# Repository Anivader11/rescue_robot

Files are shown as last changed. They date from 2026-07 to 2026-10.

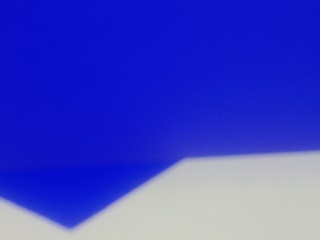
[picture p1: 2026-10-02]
rescue_robot/line_follow/cam_check.jpg

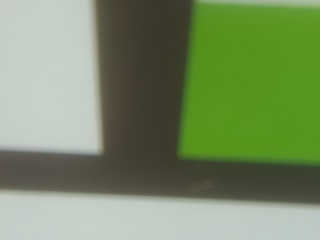
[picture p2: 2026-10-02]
rescue_robot/cam_check.jpg

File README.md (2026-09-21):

# Rescue Line Robot

RoboCup Junior Rescue Line robot running on a Raspberry Pi 5. Two-wheel
differential drive on RoboMaster M2006 P36 brushless motors, with digital
IR line sensors for line following and a Pi Camera Module doing the rest
of the perception (green direction markers, silver spill/endzone tape,
obstacle confirmation).

The robot used to be camera-only for line following (see
[`old_camera_version/`](old_camera_version/)); it's since moved to
dedicated IR line sensors, with the camera now doing everything that
isn't line position: markers, spill tape, and obstacle confirmation.

## Hardware

- **Compute:** Raspberry Pi 5, SSH reachable at `nigesh@rescue.local`
- **Drive:** 2x RoboMaster M2006 P36 brushless motors via Powerful BLDC
  Driver boards over I2C (front-left `0x20`, front-right `0x19`) — rear
  motors are disconnected, robot runs 2-wheel drive
- **Line sensors:** 2x digital IR line sensors (Parallax 28034-style),
  GPIO24 (left) / GPIO23 (right), spaced so that when centered on the
  line **both** read white — the line runs between them, not under
  either one
- **Camera:** Raspberry Pi Camera Module (via `picamera2`) — green
  marker detection, silver spill-zone detection, obstacle confirmation
- **ToF sensor:** SteelBar Time-of-Flight distance sensor, I2C address
  `0x51` (confirmed via `i2cdetect -y 1` — the vendor example code says
  `0x50`, that's wrong for this board)
- **IMU:** Adafruit BNO085 9-DOF orientation sensor, I2C address `0x4A`
- All I2C devices share bus 1 (GPIO2/SDA, GPIO3/SCL)

## Repo layout

```
rescue_robot/
├── line_follow/              -- active robot code (see below)
├── control/
│   └── motors.py             -- BLDC motor driver + PID controller class
├── sensor_tests/              -- standalone IR line sensor test scripts
├── old_camera_version/        -- archived camera-only line-following system
├── switch_watcher.py          -- GPIO21 physical switch: turns main.py on/off
├── rescue-robot-switch.service -- systemd unit for switch_watcher.py
├── setup_pi.sh                -- Pi provisioning script
├── requirements.txt
└── FILE_MAP.md                -- more detailed file-by-file breakdown
```

## `line_follow/` — active system

**Entry point:** `pid_line_follow.py`. Run with:
```
python3 line_follow/pid_line_follow.py
```

### Core line following

Two digital IR sensors, read once per loop tick (`LEFT_PIN=24`,
`RIGHT_PIN=23`). `error = left_val - right_val` (-1, 0, or +1 — sensors
are binary, not analog). A PD controller (`Kp=20`, `Kd=10`, no I term —
not useful with a 3-valued error signal) turns that into a differential
steering correction applied to both wheels around `BASE_SPEED`. Both
`(0,0)` (centered — line between the sensors) and `(1,1)` (on an
intersection) correctly resolve to error `0` and drive straight; there's
no separate "line lost" failsafe.

### Camera subsystem — `camera_watcher.py`

Only one physical camera exists on the robot, so a single shared
`Picamera2` thread runs every camera-based check on the same captured
frame, instead of each detector opening its own camera (which would
conflict):

- **Green marker detection** — HSV threshold + largest-contour check,
  reports which side (`left`/`right`) a green marker was seen on. Resets
  to `None` when nothing's detected that frame (doesn't get stuck on the
  last reading).
- **Spill/endzone tape detection** — `spill_classifier.py`, a trained
  Random Forest classifier (95.6% test accuracy) running on features
  extracted from a fixed center box each frame. See "Spill-zone ML
  pipeline" below for how it was built. Classical CV approaches
  (brightness threshold, saturation threshold, local std-dev, top-hat
  filter) were all tried first and failed — the tape and tile are close
  to indistinguishable pixel-by-pixel; only a trained classifier over
  whole-region features worked reliably.
- **`get_frame()`** — exposes the latest raw frame so other code
  (`bottle_detector.py`) can run its own one-off check on demand without
  opening a second camera.

`green_detector.py` and `spill_detector.py` are kept as standalone
single-purpose versions of the same logic (useful for isolated testing)
but aren't imported by `pid_line_follow.py` anymore — `camera_watcher.py`
replaced both.

### Obstacle handling — ToF + camera confirmation

`tof_sensor.py` is a Python port of the SteelBar ToF sensor's I2C
protocol (register `0x10`, 5-byte read: sequence number + signed
little-endian distance in mm). `tof_detector.py` polls it in a background
thread.

The ToF alone can't tell a ramp from an actual obstacle (both can read
within 50mm), so when it triggers, `bottle_detector.py` checks the
latest camera frame before committing to anything: since the obstacle
(a 1.25L clear water bottle) has no reliable color to threshold on, it
looks for shape instead — Canny edges + a Hough line transform, checking
whether the scene is dominated by near-vertical lines (a bottle's two
side edges + its cylindrical highlight) rather than the diagonal/
horizontal edges a ramp's sloped face would produce. Only if the camera
confirms it does `obstacle_evade.py` run its fixed timed evasion
maneuver (back → right → forward → left → straight → left → right, then
resume line following); otherwise it's treated as a ramp and normal line
following just continues.

`bottle_detector.py`'s shape heuristic is untested on real hardware —
tune `MIN_VERTICAL_LINES` / `VERTICAL_LINE_RATIO_THRESHOLD` against the
actual bottle and ramp once you can test on the Pi (standalone test mode:
`python3 line_follow/bottle_detector.py`, using a laptop webcam).

### Ramp speed boost — IMU

`imu_sensor.py` wraps the Adafruit BNO085 (`adafruit-circuitpython-bno08x`)
and reports raw accelerometer/gyroscope/magnetometer values. A background
thread, `accel_speed_boost.py`, watches raw Y acceleration; level ground
reads around `Y=-9.8` (gravity), and once `Y` drops below `-15.0`
(nosing upward onto a ramp), `pid_line_follow.py` multiplies `BASE_SPEED`
by 1.5 (+50%) until `Y` comes back above the threshold.

### Spill-zone ML pipeline (how `spill_model_weights.py` was built)

1. `collect_spill_samples.py` (laptop webcam) / a Pi-side collector —
   capture labelled samples (silver tape vs. tile, including tricky
   negatives like shadows/the black line) into `spill_samples.csv`.
   Features per sample: mean R/G/B, mean H/S/V, brightness, std_dev,
   max, min, range — all measured over a fixed 150x150px center box.
2. `train_spill_classifier.py` (laptop, needs `scikit-learn`) — trains
   both `LogisticRegression` and `RandomForestClassifier`, picks whichever
   scores higher on a held-out split, and exports the winner as plain
   Python data (`spill_model_weights.py`) with **no sklearn dependency**.
3. `spill_classifier.py` — pure-numpy inference on the Pi, no sklearn
   needed at runtime. Supports both model types the trainer might export.

To retrain: collect more samples into `spill_samples.csv`, rerun
`train_spill_classifier.py`, copy the regenerated `spill_model_weights.py`
onto the Pi.

### Test/calibration utilities

- `test_forward.py` — drives both wheels forward briefly, for verifying
  `control/motors.py`'s `MOTOR_CONFIG` calibration values after a power
  cycle (the BLDC driver boards' `elec_angle_offset`/`sincos_centre`
  reset when they lose power — re-run a calibration tool and paste fresh
  values into `MOTOR_CONFIG` when that happens)
- `test_green_webcam.py`, `test_spill_webcam.py`,
  `test_spill_classifier_webcam.py` — standalone webcam test harnesses
  for the camera detectors, without needing the full robot loop running
- `calibrate_spill_webcam.py` — measures brightness/color/std-dev
  differences between the silver tape and white tile, used while
  designing the spill detection approach

## `control/motors.py`

`BLDCMotorDriver` — real I2C driver for the two front M2006 motors via
the `steelbar_powerful_bldc_driver` library. Sign convention: right side
positive, left side negative = forward. `MOTOR_CONFIG` holds per-motor
I2C address + calibration values that must be refreshed after any power
cycle of the driver boards.

Also includes `PIDController` (a more general PID used elsewhere) and
`StubMotorDriver` (prints commands instead of driving hardware, for
testing without the robot).

## `sensor_tests/`

Standalone scripts for bringing up and verifying the IR line sensors in
isolation, before they're wired into the main loop.

## `old_camera_version/`

Archived: the original all-camera line-following system (HSV-threshold
line detection instead of IR sensors, PID over camera-estimated line
position). Kept for reference; not run anymore.

## `switch_watcher.py` + `rescue-robot-switch.service`

Watches a physical GPIO21 switch: ON starts `line_follow/pid_line_follow.py`
as a subprocess, OFF stops it. Installed as a systemd service so it
starts on boot:
```
sudo cp rescue-robot-switch.service /etc/systemd/system/
sudo systemctl daemon-reload
sudo systemctl enable --now rescue-robot-switch.service
```

## Setup

```
bash setup_pi.sh                 # Pi provisioning
pip install -r requirements.txt
pip install adafruit-circuitpython-bno08x adafruit-blinka   # for imu_sensor.py
pip install git+https://github.com/Aw3someAndrew/SteelBar_CircuitPython_powerful_bldc_driver.git
```

See `FILE_MAP.md` for a more granular file-by-file reference.

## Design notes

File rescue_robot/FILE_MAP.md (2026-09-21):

# File Map — Rescue Robot Project

Current layout after pivoting from camera-based line following to digital IR
line sensors. Kept in the project root as a quick reference.

```
rescue_robot/
│
├── control/
│   └── motors.py                  ← BLDCMotorDriver, unchanged, still used
│
├── line_follow/                   ← ACTIVE line-following system
│   ├── pid_line_follow.py         ← entry point, run this to start the robot
│   └── green_detector.py          ← background camera thread, green marker side detection
│
├── sensor_tests/                  ← GPIO/sensor diagnostic scripts (reference only)
│   ├── test_28034_line_sensor.py
│   ├── test_28034_line_sensor_rawlgpio.py
│   └── test_minimal.py            ← simplest confirmed-working sensor read
│
├── switch_watcher.py              ← boot switch watcher, launches line_follow/pid_line_follow.py
├── rescue-robot-switch.service    ← systemd unit for switch_watcher.py
├── requirements.txt
├── setup_pi.sh
├── README.md
├── FILE_MAP.md                    ← this file
│
└── old_camera_version/            ← ARCHIVE, not run anymore
    ├── main.py                    ← old entry point
    ├── vision/                    ← old camera line/marker/obstacle detection
    ├── tests/
    ├── control/
    │   ├── state_machine.py       ← old robot state machine (LINE_FOLLOWING/LOST/etc)
    │   └── shared_vision.py
    ├── calib.py
    ├── calibrate.py
    ├── calibrate_obstacle.py
    ├── calibrate_once.py
    ├── calibration_offsets.json
    ├── example.py
    ├── test_drive_calibration.py
    ├── test_forward.py
    ├── test_forwardreal.py
    ├── test_forwardv2.py
    ├── test_individual.py
    ├── test_individual_livecal.py
    ├── test_turn.py
    ├── push_test_forwardv2.sh
    ├── Rescue_Line_Robot_Code_Documentation.docx
    ├── __pycache__/
    └── _to_delete/
```

## Running the robot

```bash
python3 line_follow/pid_line_follow.py
```

or just flip the physical switch (systemd runs `switch_watcher.py`, which
launches the above automatically).

## Pushing updated files to the Pi

From your laptop, inside the `rescue_robot` folder (Windows example):
```
scp "path\to\rescue_robot\line_follow\pid_line_follow.py" nigesh@rescue.local:~/rescue_robot/line_follow/pid_line_follow.py
scp "path\to\rescue_robot\line_follow\green_detector.py" nigesh@rescue.local:~/rescue_robot/line_follow/green_detector.py
```

Make sure the destination folder exists first:
```
ssh nigesh@rescue.local "mkdir -p ~/rescue_robot/line_follow ~/rescue_robot/sensor_tests"
```

## Verifying the structure is correct

```bash
find rescue_robot -name "*.py" -not -path "*/old_camera_version/*" | sort
```
Should list exactly: `control/motors.py`, `line_follow/pid_line_follow.py`,
`line_follow/green_detector.py`, `sensor_tests/test_28034_line_sensor.py`,
`sensor_tests/test_28034_line_sensor_rawlgpio.py`,
`sensor_tests/test_minimal.py`, `switch_watcher.py`.

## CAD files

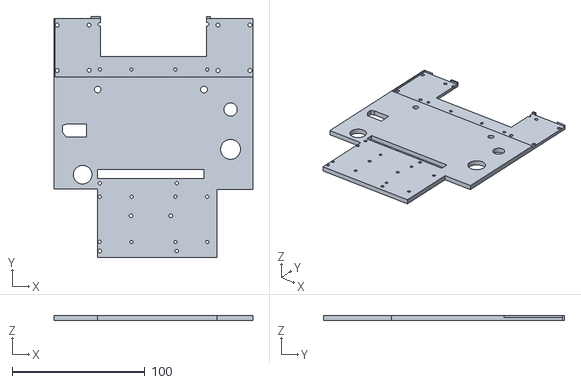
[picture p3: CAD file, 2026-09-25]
design/robot V1 main base revised.stl
149.7 x 181.4 x 4.00

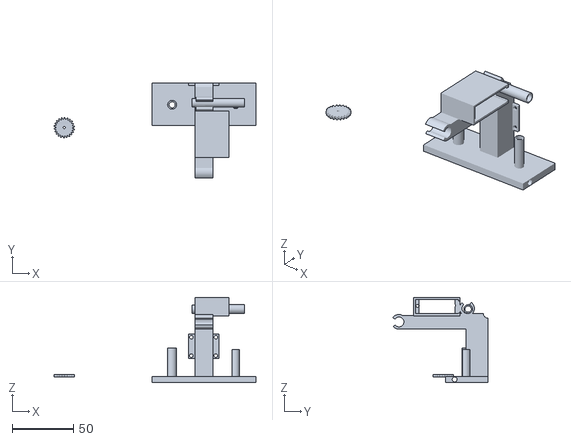
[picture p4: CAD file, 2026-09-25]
design/full_light_sensor_carriage.stl
165.0 x 77.9 x 69.5

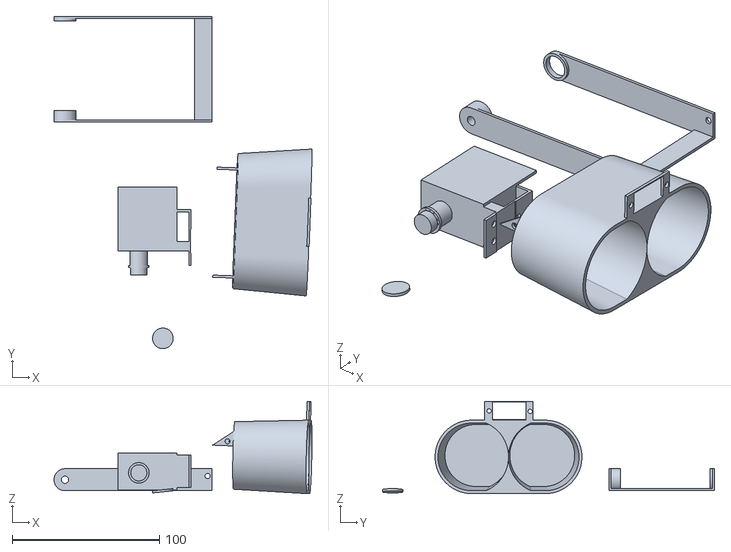
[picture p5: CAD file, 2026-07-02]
design/fullclawassembly.stl
175.5 x 226.0 x 62.8

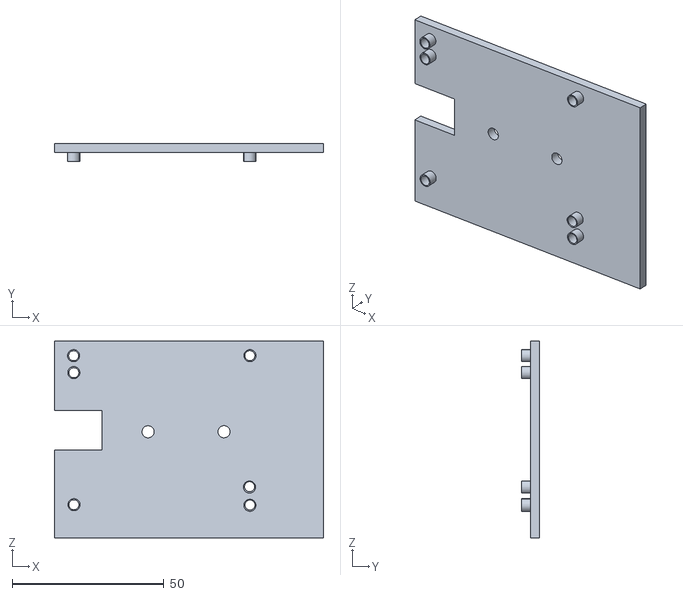
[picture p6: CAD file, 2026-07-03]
final-pi-base.stl
88.6 x 6.00 x 64.8

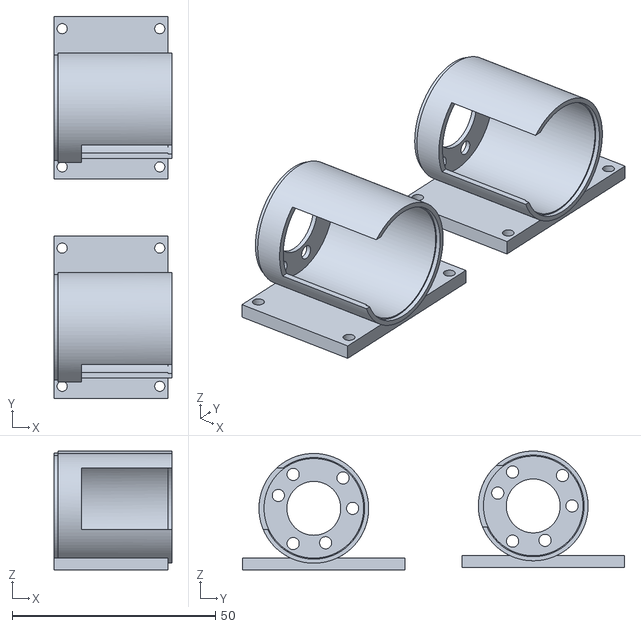
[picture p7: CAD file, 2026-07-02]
design/finalmotormount.stl
29.0 x 94.0 x 29.3

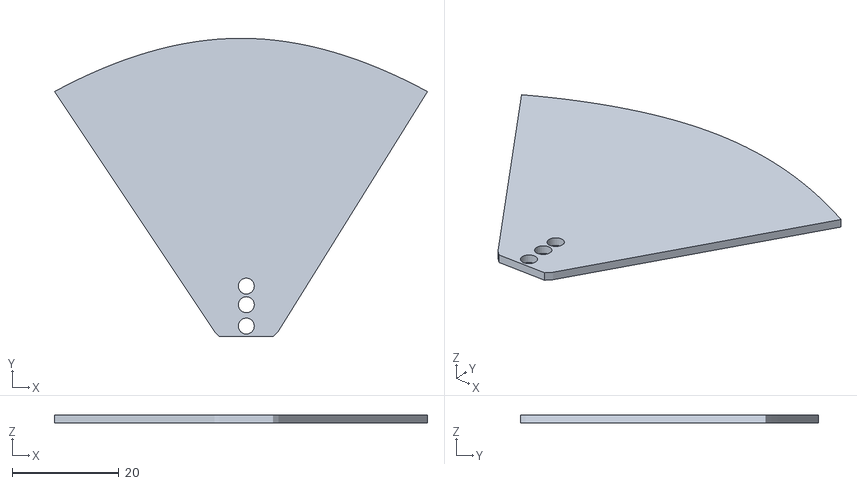
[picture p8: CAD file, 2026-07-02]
design/clawpalm.stl
70.0 x 56.0 x 1.50

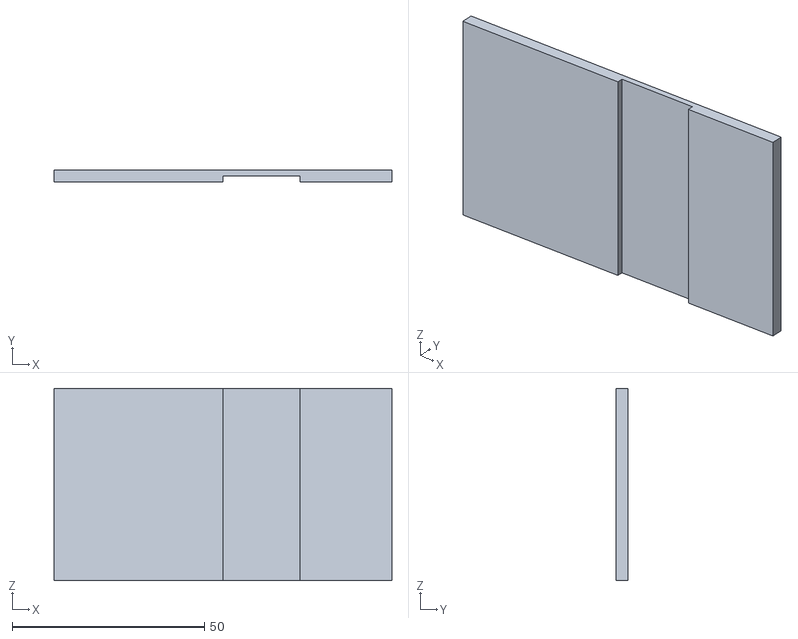
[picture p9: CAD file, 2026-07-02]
design/belowbatteryplate.stl
88.0 x 3.00 x 50.0

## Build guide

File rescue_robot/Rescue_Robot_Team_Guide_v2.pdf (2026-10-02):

Rescue Robot Team Guide | Page 1

# Rescue Robot

# Team Guide

## RoboCup Junior Australia - Open Rescue Line 2026 Melbourne High School

What is in this guide? 1. How our robot works (the simple version) 2. Setting up your laptop, then step by step: put code on the robot and run it 3. The important files and what each one does 4. The numbers you can change to make the robot behave better 5. Test scripts to check each part works 6. The problems we still have right now 7. What to do when you see an error 8. How to ask AI for help

GOOD TO KNOW: You do NOT need to understand all the code. You only need to know which file to run, how to copy it to the robot, and which number to change. This guide shows you all three. Everything here is done from your own laptop.

# 1. How our robot works

### Think of the robot as having eyes, a brain and muscles:

Part | What it is | What it does
Brain | Raspberry Pi (name: rescue.local) | Runs our Python code. We log in to it from a laptop.
Line eyes | 8 IR sensors in a row under the front (Parallax #28034) | Each sensor says black (1) or white (0). Together they tell us where the black line is.
Camera | Pi camera on a servo arm | Sees green squares, the silver tape, balls and the coloured triangles.
Distance sensor | ToF sensor, 19 mm off the floor, at the front | Measures how far away something is in front (in mm).
Tilt sensor | IMU (BNO085) | Tells us when we are going up a ramp so we can speed up.
Muscles | 2 front wheel motors (rear right motor is broken) | Drive and turn the robot.
Claw | On the BACK of the robot. 2 servos: open/close + lift | Picks up balls in the evacuation zone.

How line following works, in one sentence: 80 times every second, the robot reads the 8 sensors, works out how far the line is from the middle, and steers back toward it. The further off the line is, the harder it steers. This is called PID.
The error number: the code turns the 8 sensors into one number called the error. 0 means the line is right in the middle. +3.5 means it is all the way at one end (OUT0), -3.5 means all the way at the other end (OUT7).

### What it does at special places:

Situation | What the robot does
Line lost (all 8 sensors white) | Spins on the spot toward the last way it was turning (LEFT or RIGHT) until it sees the line again.
Green square | Stops for 1 s, checks again which side the green is on (votes), drives forward a little, then turns that way.
Sharp 90 degree corner after a straight | Drives forward a little so the wheels reach the corner, then pivots.
U-turn / two lines seen at once | Follows only the line closest to where it was before. Slows down in sharp bends.
Silver tape (evacuation zone) | Only in pid_line_follow.py: stops, checks, then runs the endzone code.
Obstacle (bottle) | Currently TURNED OFF (USE_TOF = False).

# 2. Set up YOUR laptop (do this only once)

Everyone uses their own laptop. The Pi on the robot holds the team's real, up-to-date copy of the code. Your laptop gets a copy from the Pi, you change it, and you send it back.

GOOD TO KNOW: Think of the Pi as the team's shared notebook. Always read the newest page from it before you write, and put your page back when you are done.

## Setup 1 - Check your laptop can talk to the Pi

Windows: press the Windows key, type PowerShell, press Enter. Mac: open Terminal (Cmd + Space, type Terminal).

Type this (robot must be switched on, same Wi-Fi):

ssh nigesh@rescue.local
The first time it asks "Are you sure you want to continue connecting?" - type yes and press Enter. Then type the Pi password (ask the team). If you see nigesh@rescue:~ $, it works. Type exit to go back to your laptop.

## Setup 2 - Download the code from the Pi to your laptop

Windows PowerShell (on your laptop):

scp -r nigesh@rescue.local:~/rescue_robot "$HOME\Documents\"

Mac Terminal (on your laptop):

scp -r nigesh@rescue.local:~/rescue_robot ~/Documents/
This copies the whole rescue_robot folder into your Documents folder. -r means "copy the folder and everything inside it".

## Setup 3 - Install a code editor (recommended)

Download Visual Studio Code (free) from code.visualstudio.com. Open it, then File -> Open Folder -> Documents -> rescue_robot. You can now click on any file to read or change it. Notepad also works if you can't install anything.

## Your folder paths (use these everywhere in this guide)

Where | Folder
Your laptop (Windows) | $HOME\Documents\rescue_robot\line_follow ($HOME = your user folder)
Your laptop (Mac) | ~/Documents/rescue_robot/line_follow
The Pi | ~/rescue_robot/line_follow (~ means /home/nigesh)
Pi login | nigesh@rescue.local

CAREFUL: Only ONE person sends files to the Pi at a time. If two people change the same file on their own laptops and both copy it to the Pi, the second one wipes out the first one's change. Say in the team chat "I'm pushing pid_line_follow_no_endzone.py" before you copy.

# 2. (continued) Step by step: every time you work on the robot

The code lives in two places: on your laptop (where you edit it) and on the Pi (where it runs). When you change a file on your laptop, you must copy it to the Pi or the robot will still run the old version.

GOOD TO KNOW: Golden rule: get the latest from the Pi -> edit on your laptop -> copy back with scp -> run on the Pi.

## Step 1 - Turn on the robot and connect to the same Wi-Fi

Turn the robot on and wait about 1 minute for the Pi to start. Your laptop must be on the same network as the Pi.

## Step 2 - Open PowerShell (Windows) or Terminal (Mac) on your laptop

A window opens where you type commands. Everything in a grey box marked on your laptop goes here.

## Step 3 - Get the latest code from the Pi

Windows PowerShell (on your laptop):

scp -r nigesh@rescue.local:~/rescue_robot "$HOME\Documents\"

Mac Terminal (on your laptop):

scp -r nigesh@rescue.local:~/rescue_robot ~/Documents/
CAREFUL: This REPLACES the copy on your laptop with the Pi's copy. If you changed something on your laptop and haven't sent it to the Pi yet, send it first (Step 5) or it will be lost.

## Step 4 - Go into the code folder and make your change

Windows PowerShell (on your laptop):

cd "$HOME\Documents\rescue_robot\line_follow"

Mac Terminal (on your laptop):

cd ~/Documents/rescue_robot/line_follow
cd means "change directory" = go into that folder. Now open the file in VS Code, change the number, and save (Ctrl + S, or Cmd + S on Mac).

## Step 5 - Copy the file(s) to the Pi with scp

Copy one file (on your laptop, inside the line_follow folder):

scp pid_line_follow_no_endzone.py nigesh@rescue.local:~/rescue_robot/line_follow/

Copy ALL the main files at once (on your laptop - safest after big changes):

scp camera_servo.py camera_watcher.py zone_vision.py endzone.py claw.py test_endzone.py aim_camera.py bottle_detector.py pid_line_follow_no_endzone.py pid_line_follow.py pid_line_follow_only.py nigesh@rescue.local:~/rescue_robot/line_follow/
It will ask for the Pi's password. Type it (you will NOT see the letters appear - that is normal) and press Enter. Each file prints 100% when it worked.

CAREFUL: If a file says Permission denied, it did NOT copy. See section 7 for the fix.

## Step 6 - Log in to the Pi with ssh

On your laptop:

ssh nigesh@rescue.local
Type the password. When it works, the start of the line changes to something like nigesh@rescue:~ $. Now everything you type runs on the robot.

## Step 7 - Go to the project folder on the Pi

On the Pi (after ssh):

cd ~/rescue_robot

## Step 8 - Set the camera angle by hand

Gently move the camera arm by hand to the angle that works for line following (the one we found best). The line-following code does NOT move the camera any more, so it stays where you put it.

## Step 9 - Put the robot on the line and run the code

On the Pi - the main file to use for now:

python3 line_follow/pid_line_follow_no_endzone.py

### Check the first lines it prints. You should see something like:

[version: lost-line -> spin on the spot toward last LEFT/RIGHT turn, LOOP_HZ=80]
If you do NOT see this line, the Pi has an OLD copy. Go back to Step 5.

## Step 10 - Stop the robot

Press Ctrl + C in the window. The motors stop. Pick the robot up if it is about to fall off.

## Step 11 - Log out of the Pi

On the Pi:

exit
You are now back on your laptop.

# Other useful things to do

## Change a number (tune the robot)

1. Open the file on the laptop (e.g. in VS Code or Notepad).
2. Find the number near the TOP of the file (all the settings are at the top, in CAPITAL LETTERS).
3. Change it and save (Ctrl + S).
4. Copy it to the Pi again (Step 5).
5. Run it again (Step 9).

TIP: Only change ONE number at a time, and write down what you changed and what happened. Otherwise you will not know which change helped.

## Look at what the camera sees

On the Pi:

python3 line_follow/aim_camera.py
Type a servo number (like 0.3) and press Enter. It moves the camera, holds it there, and saves a picture. Then on your laptop (open a second PowerShell/Terminal window, go to your rescue_robot

### folder):

Windows (on your laptop):

scp nigesh@rescue.local:~/cam_check.jpg . ; start cam_check.jpg

Mac (on your laptop):

scp nigesh@rescue.local:~/cam_check.jpg . ; open cam_check.jpg
This copies the picture to the laptop and opens it. Type q on the Pi to quit aim_camera.

## Edit a file directly on the Pi (quick fix only)

On the Pi:

nano line_follow/pid_line_follow_no_endzone.py
Use the arrow keys to move. Ctrl + O then Enter = save. Ctrl + X = quit.

CAREFUL: If you edit on the Pi, your laptop copy is now old. Before you change anything on your laptop again, get the latest from the Pi first (Step 3), or your next copy will undo the Pi change.

## Where the files are

Place | Path
Your laptop (Windows) | $HOME\Documents\rescue_robot\line_follow
Your laptop (Mac) | ~/Documents/rescue_robot/line_follow
Pi | ~/rescue_robot/line_follow (~ means /home/nigesh)
Pi login | nigesh@rescue.local

# 3. The important files

All of these are in the line_follow folder unless it says otherwise.

## Files you RUN

File | What it does | Use it when...
pid_line_follow_no_endzo ne.py | Main program right now. Line following + green squares + corners + U-turns. Ignores silver tape and has NO endzone. | Testing the course. Use this one most of the time.
pid_line_follow.py | Same as above PLUS silver tape detection and the evacuation zone. | Full runs - but NOT yet (see Problems: silver detector).
pid_line_follow_only.py | ONLY line following. No camera, no green, no obstacles. | Tuning Kp / Kd / speed on plain line tiles.
test_endzone.py | Runs the evacuation zone code by itself. Put the robot at the zone entrance. | Testing balls + claw + triangles. Add a number for how many balls: test_endzone.py 3
zone_vision.py | Camera-only test in the zone. Prints balls/triangles it sees, saves ~/ez_debug.jpg. | Checking the camera can see balls/triangles BEFORE driving.
camera_watcher.py | Camera-only test. Prints green side + silver, saves ~/cam_check.jpg. | Checking green-square detection.
aim_camera.py | Move the camera servo to a number you type and save a picture. | Finding good camera angles.
../sensor_tests/test_lin e8.py | Shows the 8 line sensors live, like ..##.... | Checking the line sensor wires work.

## Helper files (other files use these - you rarely run them yourself)

File | What is inside
camera_watcher.py | Runs the camera in the background. Finds green squares and which side of the black line they are on. Also flips the picture (the camera is mounted upside down).
camera_servo.py | Moves the camera arm. Has the angle numbers LINE_VALUE and LOOK_UP_VALUE.
endzone.py | The evacuation zone plan: find ball -> drive to it -> turn 180 -> grab -> find triangle -> drop.
zone_vision.py | Finds balls (silver = alive, black = dead) and the red/green triangles in a picture.
claw.py | Open, close, lower and lift the claw.
../control/motors.py | Talks to the motor drivers. set_speeds(left, right), -100 to 100.
tof_detector.py / tof_sensor.py | Reads the distance sensor.
bottle_detector.py / obstacle_evade.py | Checks if an obstacle is a bottle, and drives around it.
accel_speed_boost.py / imu_sensor.py | Speeds up on ramps using the tilt sensor.
spill_classifier.py / spill_model_weights.py | The trained 'is this silver tape?' detector.

GOOD TO KNOW: Files ending in .bak... are backups of older versions. If a change made things worse, you can copy the backup back. Do not delete them yet.

# 4. The numbers you can change (tuning)

### All of these are near the top of pid_line_follow_no_endzone.py (and the same names are in

pid_line_follow.py and pid_line_follow_only.py - change all of them so they match).

## Line following

Name | Now | What it means | If the robot... then...
BASE_SPEED | 30 | Normal forward speed (0-100). | goes off on bends -> lower it. Too slow -> raise it.
Kp | 15 | How hard it steers for how far off the line is. | is late into corners -> raise. Zig-zags on straights -> lower.
Kd | 15 | Extra kick when the line moves suddenly; also calms wobbles. | wobbles after turns -> raise. Is jerky -> lower.
LOOP_HZ | 80 | How many times per second it reads the sensors. | Leave it.
JUNCTION_MIN_BLACK | 6 | This many sensors black in a row = a junction, drive straight. | Leave it.

## When the line is lost

Name | Now | What it means | If the robot... then...
LOST_TURN_SPEED | 25 | How fast it spins on the spot to find the line. | overshoots the line -> lower. Too slow -> raise.
TURN_DIR_MIN_CORRECTION | 10 | How big a steer counts as a real LEFT or RIGHT turn. | remembers the wrong direction after a wobble -> raise to 15-20.

## Slowing down in sharp bends (U-turns)

Name | Now | What it means | If the robot... then...
MIN_SPEED_FRAC | 0.35 | Slowest speed in sharp bends, as a part of BASE_SPEED (0.35 x 30 = about 10). | still runs off U-turns -> lower to 0.25. Stalls in bends -> raise.
SLOWDOWN_START_ERR | 1.0 | Starts slowing down when the line is this far off centre. | slows too often -> raise to 1.5.
SLOWDOWN_FULL_ERR | 3.0 | Slowest when the line is this far off centre. | Usually leave it.

## Sharp corners

Name | Now | What it means | If the robot... then...
CORNER_ENABLED | True | Turn the corner routine on/off. | does strange things at corners -> set False.
CORNER_FORWARD_S | 0.25 | Seconds to drive forward before pivoting at a corner. | U-turns at a corner -> raise. Overshoots -> lower.
CORNER_MIN_STRAIGHT_S | 0.4 | Must have been going straight this long first. | corner routine never prints 'corner' -> lower.

## Green squares

Name | Now | What it means | If the robot... then...
GREEN_STOP_S | 1.0 | Stops this long after seeing green (and votes left/right). | Leave it.
GREEN_FORWARD_S | 0.4 | Drives forward this long before turning. | turns too early -> raise (0.5, 0.6...). Too late -> lower.

Name | Now | What it means | If the robot... then...
GREEN_TURN_DURATION_S | 0.6 | How long the green turn lasts. | under-turns -> raise. Over-turns -> lower.
GREEN_TURN_SPEED | 30 | How fast it turns at green. | Usually leave it.
GREEN_COOLDOWN_S | 0.8 | Ignores green for this long after a green turn. | misses a 2nd square right after -> lower.
GREEN_SWAP_TURN | False | Swap the turn direction. | says 'turning left' but turns right -> set True.

## Camera and obstacles

Name (file) | Now | What it means
SET_CAMERA_ANGLE (pid files) | False | False = the code does not move the camera at the start. You set it by hand.
LINE_VALUE (camera_servo.py) | 0.30 | Camera angle the code goes BACK to after an obstacle check / the endzone. Should match your hand angle (find it with aim_camera.py).
LOOK_UP_VALUE (camera_servo.py) | 1.0 | Camera angle for looking ahead (endzone + obstacles). 1.0 is the highest the servo can go.
MIRROR_LEFT_RIGHT / FLIP_UP_DOWN (camera_watcher.py) | True / True | Turns the camera picture the right way up (the camera is mounted upside down). Do not change.
USE_TOF (pid files) | False | Obstacle checking is OFF. Set True to turn it back on.
OBSTACLE_TRIGGER_MM (pid files) | 50 | Distance (mm) that counts as 'something in front'.

## Evacuation zone (endzone.py and claw.py)

Name | Now | What it means | If the robot... then...
TURN_180_S | 1.2 | Seconds to spin for a 180 degree turn (it is timed). | turns too far / not enough -> lower / raise.
BALL_STOP_MM | 60 | Stops this far (ToF) from a ball, so the claw lands on it after the 180. | claw misses short -> lower. Hits the ball -> raise.
DROP_STOP_MM | = BALL_ST OP_MM | Same, for the triangles. | Change BALL_STOP_MM.
DROP_LOWER_FRACTION | 0.5 | How far the claw goes down when dropping (half). | ball doesn't fall in -> raise.
MAX_BALLS | 3 | How many balls to rescue. | Leave it.
TIME_BUDGET_S | 200 | Gives up on the zone after this many seconds. | Leave it.
LIFT_DOWN_TIME_S / LIFT_UP_TIME_S (claw.py) | 1.5 / 0.5 | How long the lift servo spins down / up. | claw doesn't reach the floor -> raise down time.

# 5. Test in this order

If something does not work, go back to the earliest test that fails. Run all of these on the Pi from the ~/rescue_robot folder.

# | Command (on the Pi) | What you should see

1 | python3 sensor_tests/test_line8.py | Slide black tape under the sensors: the # moves smoothly from one end to the other.
2 | python3 line_follow/pid_line_follow_only.py | Robot follows a plain line. Tune Kp/Kd here.
3 | python3 line_follow/camera_watcher.py | Hold a green square on each side of the line: it prints the correct side.
4 | python3 line_follow/pid_line_follow_no_endzone.py | Full course without the zone. Watch the printed messages.
5 | python3 line_follow/zone_vision.py | In the zone: it lists balls and triangles. Copy ~/ez_debug.jpg to the laptop and check.
6 | python3 line_follow/test_endzone.py | Rescues ONE ball.
7 | python3 line_follow/test_endzone.py 3 | Rescues all three.

## Messages the robot prints (and what they mean)

Message | Meaning
[version: ... LOOP_HZ=80] | The new code is running. If missing, the Pi has an old copy.
TURN: LEFT / TURN: RIGHT / TURN: STRAIGHT | What the robot is doing right now (only printed when it changes).
LINE LOST -> ... spinning LEFT on the spot ... | It lost the line and is spinning toward its last real turn.
LINE FOUND again | Back on the line.
GREEN seen on the right (green_x=.., line_x=..) | It saw a green square. green_x/line_x = where in the picture.
GREEN confirmed: right (votes left=2 right=19) | After the 1 s stop, the vote result. If the votes are close, the camera is unsure.
corner -> + side | The sharp-corner routine started.

# 6. Problems we still have right now

Be honest in testing: if one of these happens, it is a KNOWN problem, not your fault.

# | Problem | What it causes | What to do for now

1 | Silver detector fires on green tiles. | In pid_line_follow.py the robot could think a green square is the evacuation zone and start the endzone in the middle of the course. | Use pid_line_follow_no_endzone.py. The silver classifier needs re-training with pictures of green tiles.
2 | Green side detection is not 100%. | Sometimes turns the wrong way at green squares. | The 1 s vote helps. Send the printed votes + green_x/line_x to whoever is fixing it.
3 | Line-lost behaviour still being tuned. | Sometimes spins the wrong way or too far after losing the line. | Watch the 'LINE LOST' message: does it say the right direction? Tune LOST_TURN_SPEED.
4 | U-turn tiles and sharp corners. | Can run off the end of a hairpin or U-turn at a corner. | Tune MIN_SPEED_FRAC and CORNER_FORWARD_S.
5 | Obstacle avoidance is OFF. | The robot will drive into the bottle. | USE_TOF = False for now. Needs testing before turning on.
6 | Evacuation zone not tested on the real robot yet. | Unknown - balls, claw position and 180 turns all need tuning. | Test with zone_vision.py first, then test_endzone.py.
7 | Leaving the evacuation zone is not written yet. | After the balls, the run just ends. | Next job to code (worth 20 points).
8 | 180 turns are timed, not measured. | Turns can be too far/short on different floors or battery levels. | Tune TURN_180_S. Later: use the IMU gyro.
9 | LINE_VALUE does not match the hand-set camera angle. | After an obstacle check or the endzone, the camera may end up at the wrong angle. | Find the right number with aim_camera.py and put it in LINE_VALUE.
10 | Pi folder permissions. | scp says 'Permission denied' for some files. | See section 7.
11 | The Pi may have old copies of files. | Changes 'don't work' because they never reached the robot. | Always check the [version ...] line when the program starts.

# 7. When you see an error

You see... | It means... | Fix
Permission denied (when using scp) | You are not allowed to write into that folder on the Pi. | On the Pi run: sudo chown -R nigesh:nigesh ~/rescue_robot then try scp again. If it still fails: copy to the home folder (scp FILE nigesh@rescue.local:~/) then on the Pi: sudo cp ~/FILE ~/rescue_robot/line_follow/
ModuleNotFoundError: No module named 'something' | A file the program needs is missing on the Pi. | Copy that file (something.py) from the laptop with scp.
AttributeError: ... has no attribute ... | Two files on the Pi are different versions. | Copy ALL the main files again (Step 5, the long command).
Could not resolve hostname rescue.local | The laptop can't find the Pi. | Is the robot on? Same Wi-Fi? Wait a minute and try again.
Password asked again and again / wrong | Typed it wrong (letters are hidden). | Type slowly. Ask the team for the password.
Robot runs old behaviour | The Pi has an old copy. | Check the [version ...] line. Copy the files again.
PWMSoftwareFallback warning | Harmless. The servo uses software timing. | Ignore it.
Robot won't stop | | Ctrl + C in the window. If that fails: pick it up and switch it off.

## Team rules

1. One change at a time. Write down what you changed and what happened.
2. Get the latest from the Pi first, edit on your laptop, then copy back. Say in the team chat before you copy.
3. Check the [version ...] line every time you run.
4. Do not use sudo to run the scripts or copy files unless this guide says so (it causes the permission problem).
5. Keep a hand near the robot - be ready to press Ctrl + C or pick it up.
6. Do not delete .bak files - they are our undo button.
7. Only one person pushes files to the Pi at a time.

# 8. How to ask AI for help

You can use any AI chat (ChatGPT, Claude, Gemini, Copilot...). The AI does not know our robot, so the most important thing is to give it the right information. Follow these steps.

## Step 1 - Start a NEW chat and paste this first

### Copy this whole box into the chat as your first message (fill in the [brackets]):

I'm on a school RoboCup Junior Rescue Line team (Open division). Robot: Raspberry Pi 5, Python 3, 2 front wheel BLDC motors (set_speeds(left, right), -100..100), 8-sensor digital IR line array (Parallax 28034, black=1), Pi camera on a servo (image rotated 180 deg in camera_watcher.py), ToF distance sensor, rear claw with 2 servos. Main program: line_follow/pid_line_follow_no_endzone.py
I'll paste the file and our team guide. Please:
- explain things simply, I'm not an expert
- suggest the SMALLEST change that fixes the problem
- tell me exactly which line / setting to change and to what
- don't rewrite the whole file unless I ask
My problem: [describe it]

## Step 2 - Give it the files

Attach (or copy-paste) the whole file you are working on, e.g. pid_line_follow_no_endzone.py. If the problem is about the camera, also attach camera_watcher.py; for the zone, endzone.py and zone_vision.py. You can also attach this PDF so it knows how our robot works.

TIP: Get the file from YOUR laptop's rescue_robot folder - but get the latest from the Pi first (Step 3), so the AI sees the code that is actually on the robot.

## Step 3 - Describe the problem like a detective

Tell the AI... | Example
What you did | Ran pid_line_follow_no_endzone.py on the U-turn tile.
What you expected | It should follow the line round the U-turn.
What actually happened | It drove off the top of the U and spun right forever.
What it printed (copy-paste ALL of it) | LINE LOST -> last turn was RIGHT -> spinning RIGHT ...
Any error message (copy-paste ALL of it) | Traceback (most recent call last): ... AttributeError: ...
Settings you changed recently | Kp from 50 to 15, LOST_TURN_SPEED 25.
A photo or video, if you can | Photo of the tile, or a cam_check.jpg picture.

## Step 4 - Before you use the AI's answer, make a backup

Windows (on your laptop, in line_follow):

copy pid_line_follow_no_endzone.py pid_line_follow_no_endzone.py.bak_mychange

Mac (on your laptop, in line_follow):

cp pid_line_follow_no_endzone.py pid_line_follow_no_endzone.py.bak_mychange

## Step 5 - Make the change, check it, test it

1. Make the change in VS Code and save.
2. Copy it to the Pi (Step 5 in section 2).

### 3. On the Pi, check there are no typing mistakes in the code:

On the Pi:

python3 -m py_compile line_follow/pid_line_follow_no_endzone.py
No message = OK. If it shows an error, paste that error back to the AI.
4. Run the robot and test.

## Step 6 - Tell the AI what happened

Say "it worked" or "it's still doing X, here is what it printed: ...". Keep going in the same chat for the same problem, so it remembers. Start a new chat for a new problem.

## Step 7 - If it got worse, undo

Windows (on your laptop):

copy pid_line_follow_no_endzone.py.bak_mychange pid_line_follow_no_endzone.py
(Mac: use cp instead of copy.) Then copy it to the Pi again.

### AI rules

1. Never paste the Pi password (or any password) into an AI.
2. The AI can be wrong. It has never seen our robot. Always test, and check the robot still does the things that worked before.
3. Ask it to explain the change in simple words. If you don't understand it, ask again.
4. One change at a time, and write down what you changed.
5. Tell the team what you changed and push it to the Pi (one person at a time).

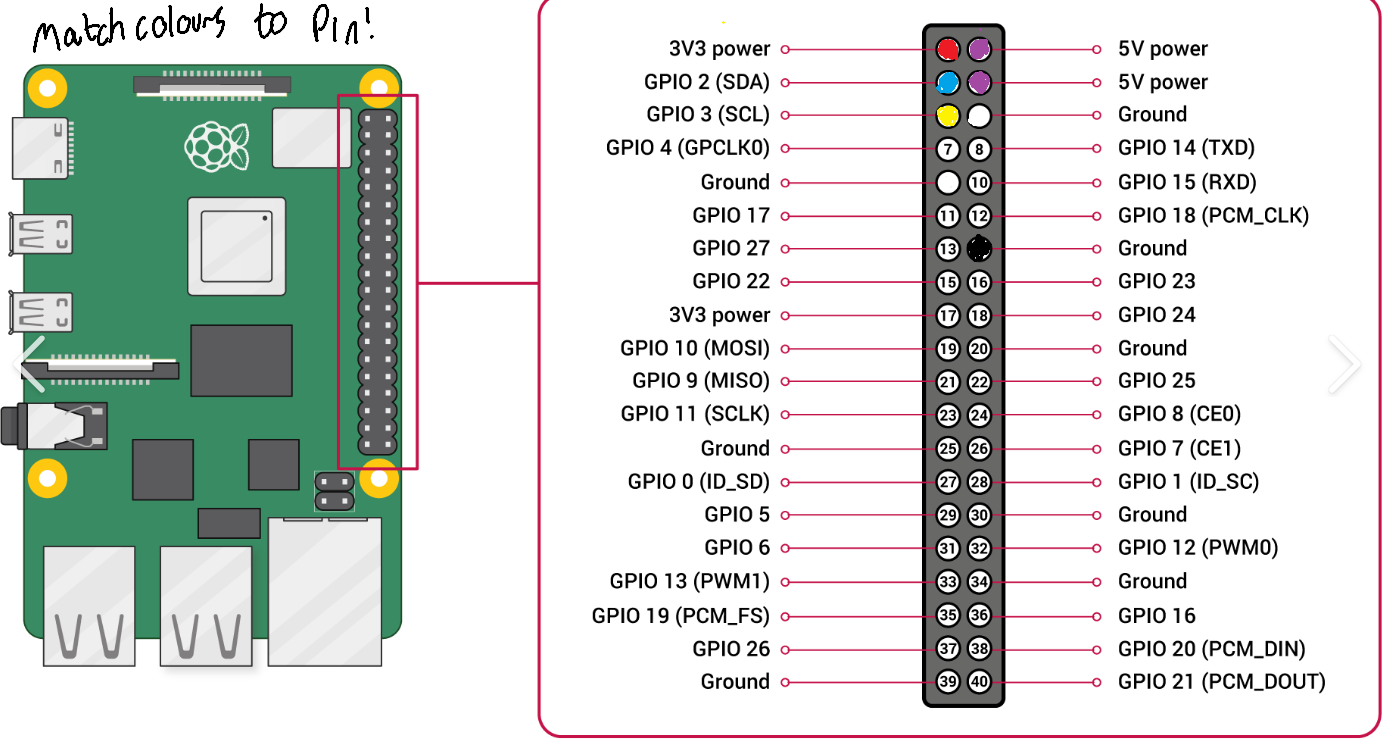
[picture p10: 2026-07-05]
design/gpio wiring diagram.png

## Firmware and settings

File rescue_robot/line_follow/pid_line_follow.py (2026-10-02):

"""
pid_line_follow.py
===================
Simple PID line follower for 2-wheel drive, using 2 digital IR line
sensors (Parallax 28034-style) instead of the camera.

Sensor power: the line sensor board has an EN (enable) pin -- BCM22 --
that must be driven HIGH before the OUT pins will report anything
real. Without this, the sensors are simply unpowered.

Sensor pins are claimed with an internal pull-up (lgpio.SET_PULL_UP) --
this is the exact setup confirmed working in sensor_tests/test_line.py.
WHITE -> LOW (0), BLACK -> HIGH (1).

Sensors: all 8 outputs of the Parallax #28034 array are read (see
SENSOR_PINS). The line's position is the average weight of the sensors
on black (-3.5..+3.5) and feeds the PID. All 8 white = line lost: if it
was last seen off to one side the robot keeps turning that way (turn
memory); if it was last near the middle it's treated as a gap and the
robot drives straight. 6+ sensors on black = junction -> straight.

Green marker handling:
    The shared camera thread (camera_watcher.py) watches for a green
    marker off to one side. When seen, the robot ignores the line
    sensors for a short fixed turn, then resumes normal PID following.

Spill/endzone handling:
    The shared camera thread (camera_watcher.py) also runs a trained
    classifier (see spill_classifier.py / spill_model_weights.py) that
    watches for the silver spill-zone tape. Endzone logic itself isn't
    built yet -- for now, as soon as it's seen, the robot stops and
    double-checks for SPILL_VERIFY_S before trusting it: if the
    classifier still says spill after that pause, it's treated as
    confirmed (prints a message, stops for good, run ends there). If it
    was a false alarm (e.g. a shadow or the black line fooling the
    classifier), the robot just resumes normal line following.
    Once confirmed, endzone.py's run_endzone() takes over (find ball ->
    ToF distance -> pause -> 180 -> grab -> matching triangle -> drop,
    x3). Leaving the zone isn't built yet, so the run still ends after.

Obstacle handling:
    A background thread (tof_detector.py) polls the SteelBar ToF
    distance sensor (tof_sensor.py). The ToF alone can't tell a ramp
    apart from an actual obstacle -- both can read within
    OBSTACLE_TRIGGER_MM -- so as soon as it triggers, the robot grabs
    the latest camera frame (from the shared camera_watcher.py thread)
    and runs bottle_detector.py's shape check on it before doing
    anything. Only if that confirms it looks like the bottle (not a
    flat/angled ramp surface) does it run the fixed timed evasion
    maneuver (obstacle_evade.py: back, right, forward, left, straight,
    left, right). If the camera doesn't confirm it, it's treated as a
    ramp and the ToF trigger is ignored -- normal line following (with
    the accelerometer ramp speed boost below) just continues.

Ramp/IMU handling:
    A background thread (accel_speed_boost.py) polls the BNO085's raw
    Y acceleration (imu_sensor.py). Whenever Y drops below
    ACCEL_Y_BOOST_THRESHOLD (-15 m/s^2 by default -- flat/level sits
    around -9.8 from gravity, so this fires once the robot noses
    upward enough on a ramp), BASE_SPEED is scaled up by
    ACCEL_SPEED_BOOST_MULTIPLIER. Returns to normal speed the instant
    Y comes back above the threshold.
"""

import time
import sys
import os

sys.path.insert(0, os.path.dirname(os.path.dirname(os.path.abspath(__file__))))
import lgpio
from control.motors import BLDCMotorDriver
from camera_watcher import CameraWatcher
from tof_detector import ToFDetector
from obstacle_evade import run_evade_sequence
from bottle_detector import is_bottle
from accel_speed_boost import AccelSpeedBoost
from camera_servo import CameraServo
from endzone import run_endzone

EN_PIN = 22    # line sensor array's enable line -- must be driven HIGH or the sensors don't power up at all

# --- 8-sensor array (Parallax #28034), wiring confirmed with sensor_tests/test_line8.py ---
#              OUT0 OUT1 OUT2 OUT3 OUT4 OUT5 OUT6 OUT7
SENSOR_PINS = [5,   6,   24,  16,  17,  23,  25,  26]

# Position weight per sensor. Sign chosen to match the old, confirmed-working
# 2-sensor code: OUT2 (old left pin, BCM24) on black gave a POSITIVE error,
# OUT5 (old right pin, BCM23) a NEGATIVE one -- so the OUT0 end is positive.
# If the robot steers AWAY from the line, flip LINE_SIGN to -1.
LINE_SIGN = 1
WEIGHTS = [3.5, 2.5, 1.5, 0.5, -0.5, -1.5, -2.5, -3.5]

# --- Line lost: turn ON THE SPOT toward the last left/right turn ---
LOST_TURN_SPEED = 25.0           # spin speed while searching (one wheel +, other -)
TURN_DIR_MIN_CORRECTION = 10.0   # correction at least this big counts as turning left/right

# --- Slow down in sharp turns (U-turn hairpins, tight bends) ---
SLOWDOWN_START_ERR = 1.0   # line this far off centre (or less) -> full speed
SLOWDOWN_FULL_ERR = 3.0    # line this far off centre (or lost) -> slowest
MIN_SPEED_FRAC = 0.35      # slowest = this fraction of BASE_SPEED (30 -> ~10)
JUNCTION_MIN_BLACK = 6     # this many+ sensors on black = junction / wide black -> go straight

# --- Sharp 90-degree corner straight after a long straight -------------------
# (e.g. the top-right corner of the double-corner tile, where the robot used to
# spin on the spot 5 cm short of the corner and U-turn back down the line).
# Only fires when the robot HAD been driving straight for CORNER_MIN_STRAIGHT_S
# and then half the array suddenly goes black on ONE side. Everything else
# (curves, corners that come straight after another turn) is normal PID.
CORNER_ENABLED = True
CORNER_MIN_STRAIGHT_S = 0.4   # must have been straight (|error| <= 1) this long first
CORNER_MIN_BLACK = 4          # 4+ black incl. one END sensor (other end white) = corner
CORNER_FORWARD_SPEED = 30.0
CORNER_FORWARD_S = 0.25       # TUNE: drive on this long so the wheels reach the corner (~5 cm)
CORNER_PIVOT_SPEED = 45.0
CORNER_PIVOT_MIN_S = 0.1
CORNER_PIVOT_TIMEOUT_S = 2.0

BASE_SPEED = 30.0
Kp = 15.0   # tuned on the robot
Kd = 15.0

GREEN_STOP_S = 1.0           # after seeing green: stop completely this long,
GREEN_FORWARD_S = 0.4        # ...then drive straight this long (TUNE: higher = turns later),
GREEN_FORWARD_SPEED = 30.0   # ...THEN do the turn
GREEN_TURN_DURATION_S = 0.6
GREEN_TURN_SPEED = 30.0
GREEN_SWAP_TURN = False      # set True if it says 'turning left' but physically spins right
GREEN_COOLDOWN_S = 0.8   # was 2.0 -- too long, skipped the 2nd square straight after a turn

# --- Spill/endzone verification tunables ---
SPILL_VERIFY_S = 1.0
SPILL_FALSE_ALARM_COOLDOWN_S = 1.0

# --- Obstacle (ToF) tunables ---
SET_CAMERA_ANGLE = False      # False = don't touch the camera at start; set its angle BY HAND before running
USE_TOF = False               # False = ToF obstacle check off (no evasion at all)
OBSTACLE_TRIGGER_MM = 50
OBSTACLE_STALE_S = 0.5           # ignore ToF readings older than this (sensor stuck/disconnected)
OBSTACLE_COOLDOWN_S = 1.0        # after an evade (or a ramp false-alarm), ignore new triggers briefly
OBSTACLE_CAMERA_SETTLE_S = 0.4  # wait after raising the camera so the next frame is from the new angle
OBSTACLE_FRAME_STALE_S = 0.5     # ignore camera frames older than this when confirming

# --- Ramp speed boost (accelerometer) tunable ---
ACCEL_SPEED_BOOST_MULTIPLIER = 1.5   # +50% speed while accel_speed_boost.py reports boosted

LOOP_HZ = 80
LOOP_SLEEP = 1.0 / LOOP_HZ


def vote_green_side(cam_watcher, first_side, duration_s):
    """While the robot is stopped, keep reading the camera for duration_s and
    take a majority vote of left/right. Readings where the black line was
    actually found (line_x not None) count; if none had a line, all readings
    count. Falls back to first_side if nothing is seen at all."""
    with_line = {"left": 0, "right": 0}
    no_line = {"left": 0, "right": 0}
    end = time.monotonic() + duration_s
    last_seen = None
    while time.monotonic() < end:
        side, seen_at = cam_watcher.get_green()
        if side is not None and seen_at != last_seen:   # only count NEW frames
            last_seen = seen_at
            _gx, lx = cam_watcher.get_green_debug()
            (with_line if lx is not None else no_line)[side] += 1
        time.sleep(0.02)
    votes = with_line if sum(with_line.values()) > 0 else no_line
    if sum(votes.values()) == 0:
        return first_side, votes
    return ("right" if votes["right"] > votes["left"] else "left"), votes


def read_vals(h):
    return [lgpio.gpio_read(h, p) for p in SENSOR_PINS]   # 1 = black


def corner_side(vals):
    """+1 / -1 (same sign convention as the PID error) if this reading looks
    like a sharp corner -- half the array black off one end -- else None."""
    if sum(vals) < CORNER_MIN_BLACK or len(_runs(vals)) != 1:
        return None   # too few black, or two separate lines (e.g. U-turn hairpin)
    if vals[0] and not vals[-1]:
        end_weight = WEIGHTS[0]
    elif vals[-1] and not vals[0]:
        end_weight = WEIGHTS[-1]
    else:
        return None   # both ends black (T / cross) or neither
    return 1 if LINE_SIGN * end_weight > 0 else -1


def run_corner(h, motors, side):
    """Drive forward so the wheels reach the corner, then pivot toward `side`
    until the middle sensors sit on the new line (and it crosses the array,
    i.e. only a few sensors black)."""
    print(f"corner -> {'+' if side > 0 else '-'} side")
    motors.set_speeds(CORNER_FORWARD_SPEED, CORNER_FORWARD_SPEED)
    time.sleep(CORNER_FORWARD_S)

    if side > 0:
        motors.set_speeds(CORNER_PIVOT_SPEED, -CORNER_PIVOT_SPEED)
    else:
        motors.set_speeds(-CORNER_PIVOT_SPEED, CORNER_PIVOT_SPEED)

    start = time.monotonic()
    while time.monotonic() - start < CORNER_PIVOT_TIMEOUT_S:
        vals = read_vals(h)
        mid = len(vals) // 2
        on_line = (vals[mid - 1] or vals[mid]) and sum(vals) <= 3
        if on_line and time.monotonic() - start >= CORNER_PIVOT_MIN_S:
            break
        time.sleep(0.005)


def _runs(vals):
    """Split the 8 readings into groups of neighbouring black sensors.
    Returns a list of index lists, e.g. [[1,2],[5,6]] for two separate lines."""
    runs, cur = [], []
    for i, v in enumerate(vals):
        if v:
            cur.append(i)
        elif cur:
            runs.append(cur); cur = []
    if cur:
        runs.append(cur)
    return runs


def read_line_error(vals, last_error):
    """Returns (error, n_black) from the 8-sensor array.
    error ~ -3.5..+3.5 = where the line is; n_black == 0 means the line is
    lost (the main loop then turns the last turning direction);
    None at a junction (caller drives straight and keeps last_error).

    If the array sees MORE THAN ONE separate line (e.g. both legs of a U-turn
    hairpin, or a nearby crossing), it follows only the group closest to
    where the line was last time instead of averaging them together."""
    runs = _runs(vals)
    n = sum(len(r) for r in runs)

    if n == 0:
        # All white = line lost. Always keep turning toward the side the line
        # was last seen on, until it's found again. (Only if it was seen dead
        # centre, with no side at all, does it drive straight.)
        return 0.0, 0         # lost -- the main loop handles it (turns the last turning direction)

    if max(len(r) for r in runs) >= JUNCTION_MIN_BLACK:
        return None, n

    run_errors = [LINE_SIGN * sum(WEIGHTS[i] for i in r) / len(r) for r in runs]
    if len(run_errors) == 1:
        return run_errors[0], n
    ref = max(-3.5, min(3.5, last_error))          # where the line was last time
    return min(run_errors, key=lambda e: abs(e - ref)), n


def turn_speed_scale(error):
    """Slow down in sharp turns: full BASE_SPEED while the line is near the
    middle, dropping to MIN_SPEED_FRAC of it when the line is at the edge of
    the array or lost -- so tight bends (U-turn hairpins) become near-pivots."""
    if error is None:
        return 1.0
    e = abs(error)
    if e <= SLOWDOWN_START_ERR:
        return 1.0
    if e >= SLOWDOWN_FULL_ERR:
        return MIN_SPEED_FRAC
    t = (e - SLOWDOWN_START_ERR) / (SLOWDOWN_FULL_ERR - SLOWDOWN_START_ERR)
    return 1.0 - t * (1.0 - MIN_SPEED_FRAC)


def main():
    h = lgpio.gpiochip_open(0)
    lgpio.gpio_claim_output(h, EN_PIN, 1)   # EN HIGH -- enable the sensor array before we try reading it
    # Internal pull-up on all 8 sensor pins -- confirmed working in
    # sensor_tests/test_line.py. WHITE -> LOW (0), BLACK -> HIGH (1).
    for pin in SENSOR_PINS:
        lgpio.gpio_claim_input(h, pin, lgpio.SET_PULL_UP)

    motors = BLDCMotorDriver()

    cam_servo = None
    if SET_CAMERA_ANGLE:
        cam_servo = CameraServo()
        cam_servo.look_at_line()     # held for the whole run

    cam_watcher = CameraWatcher()
    cam_watcher.start()

    tof_detector = ToFDetector()
    tof_detector.start()

    accel_boost = AccelSpeedBoost()
    accel_boost.start()

    handled_seen_at = 0.0
    turn_until = 0.0
    turn_side = None
    cooldown_until = 0.0
    spill_cooldown_until = 0.0
    obstacle_cooldown_until = 0.0

    last_error = 0.0
    straight_since = time.monotonic()
    was_lost = False
    last_turn_dir = None     # last real turn: "left" / "right" (STRAIGHT never overwrites it)
    current_dir = "straight" # what it is doing right now (printed when it changes)

    print(f"[version: lost-line -> spin on the spot toward last LEFT/RIGHT turn, LOOP_HZ={LOOP_HZ}]")
    print("Starting PID line follow with green marker turns, spill-zone stop, and obstacle evasion. Ctrl-C to stop.")
    try:
        while True:
            now = time.monotonic()

            # --- ToF within range: confirm with the camera before evading ---
            # (the ToF alone can't tell a ramp from an actual obstacle)
            if USE_TOF and now >= obstacle_cooldown_until:
                distance_mm, seen_at = tof_detector.get_latest()
                fresh = distance_mm is not None and (now - seen_at) <= OBSTACLE_STALE_S
                if fresh and distance_mm <= OBSTACLE_TRIGGER_MM:
                    motors.stop()
                    # Raise the camera so it actually looks AT the obstacle, not the floor.
                    obs_servo = CameraServo()
                    obs_servo.look_up()
                    time.sleep(OBSTACLE_CAMERA_SETTLE_S)
                    frame, frame_seen_at = cam_watcher.get_frame()
                    frame_fresh = frame is not None and (time.monotonic() - frame_seen_at) <= OBSTACLE_FRAME_STALE_S
                    bottle = frame_fresh and is_bottle(frame)
                    # Put the camera back to the line-following angle and let the servo go.
                    obs_servo.look_at_line()
                    obs_servo.release()

                    if bottle:
                        run_evade_sequence(motors)
                    else:
                        print("ToF triggered but camera didn't confirm a bottle -- treating as ramp")

                    obstacle_cooldown_until = time.monotonic() + OBSTACLE_COOLDOWN_S
                    last_error = 0.0
                    continue

            # --- Possible spill/endzone tape: stop and verify before trusting it ---
            if now >= spill_cooldown_until:
                spill_seen, _ = cam_watcher.get_spill()
                if spill_seen:
                    print("possible spill detected -- stopping to verify...")
                    motors.stop()
                    time.sleep(SPILL_VERIFY_S)

                    spill_seen_confirmed, _ = cam_watcher.get_spill()
                    if spill_seen_confirmed:
                        print("endzone detected -- running evacuation zone logic")
                        motors.stop()
                        if cam_servo is not None:      # endzone takes over the camera servo
                            cam_servo.close()
                            cam_servo = None
                        run_endzone(motors, cam_watcher, tof_detector)
                        motors.stop()
                        break   # exit + line reacquire not built yet
                    else:
                        print("false alarm -- resuming")
                        spill_cooldown_until = time.monotonic() + SPILL_FALSE_ALARM_COOLDOWN_S
                        continue

            # --- Currently mid-turn: ignore line sensors entirely ---
            if turn_until > 0.0:
                if now < turn_until:
                    if (turn_side == "right") != GREEN_SWAP_TURN:
                        motors.set_speeds(GREEN_TURN_SPEED, -GREEN_TURN_SPEED)
                    else:
                        motors.set_speeds(-GREEN_TURN_SPEED, GREEN_TURN_SPEED)
                    time.sleep(LOOP_SLEEP)
                    continue
                else:
                    turn_until = 0.0
                    turn_side = None
                    cooldown_until = now + GREEN_COOLDOWN_S
                    last_error = 0.0

            if now >= cooldown_until:
                side, seen_at = cam_watcher.get_green()
                if side is not None and seen_at != handled_seen_at:
                    handled_seen_at = seen_at
                    gx, lx = cam_watcher.get_green_debug()
                    print(f"GREEN seen on the {side} (green_x={gx}, line_x={lx}) -- stopping to confirm...")
                    motors.stop()
                    # Use the stop time to look again and take a majority vote,
                    # so one bad frame can't send it the wrong way.
                    side, votes = vote_green_side(cam_watcher, side, GREEN_STOP_S)
                    print(f"GREEN confirmed: {side} (votes left={votes['left']} right={votes['right']}) -- forward {GREEN_FORWARD_S}s, then turning {side}")
                    motors.set_speeds(GREEN_FORWARD_SPEED, GREEN_FORWARD_SPEED)
                    time.sleep(GREEN_FORWARD_S)
                    turn_side = side
                    turn_until = time.monotonic() + GREEN_TURN_DURATION_S
                    continue

            vals = read_vals(h)

            # Sharp corner straight after a long straight: drive up to it, then pivot.
            if CORNER_ENABLED and time.monotonic() - straight_since >= CORNER_MIN_STRAIGHT_S:
                side = corner_side(vals)
                if side is not None:
                    run_corner(h, motors, side)
                    last_error = 0.0
                    straight_since = time.monotonic()
                    continue

            error, _n_black = read_line_error(vals, last_error)
            lost_now = _n_black == 0

            if lost_now and not was_lost:
                if last_turn_dir:
                    how = ("it was going STRAIGHT, so looked back -> last real turn was "
                           if current_dir == "straight" else "last turn was ")
                    print(f"LINE LOST -> {how}{last_turn_dir.upper()} -> spinning {last_turn_dir.upper()} on the spot until the line is seen")
                else:
                    print("LINE LOST -> no LEFT/RIGHT turn recorded yet -> creeping straight forward")
            elif was_lost and not lost_now:
                print("LINE FOUND again")
            was_lost = lost_now

            if lost_now:
                # No PID while lost: spin ON THE SPOT toward the last real turn
                if last_turn_dir == "right":
                    motors.set_speeds(LOST_TURN_SPEED, -LOST_TURN_SPEED)
                elif last_turn_dir == "left":
                    motors.set_speeds(-LOST_TURN_SPEED, LOST_TURN_SPEED)
                else:
                    motors.set_speeds(10.0, 10.0)   # nothing recorded yet: creep forward to find a line
                time.sleep(LOOP_SLEEP)
                continue

            if error is None:          # junction: straight, keep memory
                correction = 0.0
            else:
                correction = Kp * error + Kd * (error - last_error)
                last_error = error
                # What is the robot doing right now: LEFT, RIGHT or STRAIGHT?
                if correction >= TURN_DIR_MIN_CORRECTION:
                    now_dir = "right"
                elif correction <= -TURN_DIR_MIN_CORRECTION:
                    now_dir = "left"
                else:
                    now_dir = "straight"
                if now_dir != current_dir:
                    print(f"TURN: {now_dir.upper()}")
                    current_dir = now_dir
                # If it's STRAIGHT, keep the previous LEFT/RIGHT -- i.e. look back
                # through the history to the last real turn.
                if now_dir != "straight":
                    last_turn_dir = now_dir

            if error is None or abs(error) > 1.0:
                straight_since = time.monotonic()   # not driving straight

            is_boosted, _accel_y = accel_boost.get_boost()
            base_speed = BASE_SPEED * ACCEL_SPEED_BOOST_MULTIPLIER if is_boosted else BASE_SPEED
            base_speed *= turn_speed_scale(error)

            left_speed = base_speed + correction
            right_speed = base_speed - correction
            motors.set_speeds(left_speed, right_speed)

            time.sleep(LOOP_SLEEP)
    except KeyboardInterrupt:
        print("\nStopped.")
    finally:
        motors.stop()
        if cam_servo is not None:
            cam_servo.close()
        cam_watcher.stop()
        tof_detector.stop()
        accel_boost.stop()
        lgpio.gpio_write(h, EN_PIN, 0)   # EN LOW -- power the sensor array back down on exit
        lgpio.gpiochip_close(h)


if __name__ == "__main__":
    main()

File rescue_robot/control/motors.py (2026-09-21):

"""
motors.py
=========
Motor driver for the robot's two front RoboMaster M2006 P36 brushless
motors via I2C, using the Powerful BLDC Driver boards.

TWO WHEEL DRIVE — the rear right motor failed, so the robot now runs on
just the two FRONT motors (LEFT_FRONT, RIGHT_FRONT). Both rear motors are
disconnected/unused; MOTOR_CONFIG below only lists the two front ones.
Steering still works the same way as before (differential drive between
left and right), just with one wheel per side instead of two.

Kept deliberately simple: BLDCMotorDriver below is a straight port of
test_forwardv2.py's setup_motor() — the only script confirmed to actually
drive the robot correctly — wrapped so state_machine.py can use it through
the same MotorDriver interface as StubMotorDriver. No calibration file,
no firmware-version check, no position PID, no double-apply of constants.

Sign convention (proven by test_forwardv2.py):
    Forward = right side gets +speed, left side gets -speed.

IMPORTANT — calibration values are volatile:
    elec_angle_offset / sincos_centre in MOTOR_CONFIG below reset if the
    driver boards lose power. If the boards get power-cycled, re-run
    calibrate_once.py (or re-verify test_forwardv2.py still drives
    straight) and paste the new values into MOTOR_CONFIG here.

I2C1 on Pi GPIO pins 3 (SDA) / 5 (SCL), 1MHz — set in
/boot/firmware/config.txt:
    dtoverlay=i2c1,pins_2_3,baudrate=1000000
"""

import time
import logging
from abc import ABC, abstractmethod

log = logging.getLogger(__name__)

# Only the two front motors — rear right failed, rear left is now unused
# too so the robot drives symmetrically on one wheel per side. Same
# proven values as test_forwardv2.py's MOTOR_CONFIG for these two.
MOTOR_CONFIG = {
    "LEFT_FRONT":  {"address": 0x20, "elec_angle_offset": 1327246080, "sincos_centre": 1230},
    "RIGHT_FRONT": {"address": 0x19, "elec_angle_offset": 1185441536, "sincos_centre": 1248},
}

SPEED_LIMIT     = 546133333   # driver-side hard cap (test_forwardv2.py proven)
MAX_SPEED_UNITS = 25000000   # what 100% maps to == test_forwardv2.py DRIVE_SPEED
                   

# ---------------------------------------------------------------------------
# Abstract base
# ---------------------------------------------------------------------------

class MotorDriver(ABC):

    @abstractmethod
    def set_speeds(self, left: float, right: float) -> None:
        """left, right: -100.0 (full reverse) .. 0 .. +100.0 (full forward)."""

    def drive(self, base_speed: float, turn: float) -> None:
        """
        Differential drive. turn > 0 → turn right, turn < 0 → turn left.
        Values in -100..100 percentage range.
        """
        left  = max(-100.0, min(100.0, base_speed + turn))
        right = max(-100.0, min(100.0, base_speed - turn))
        self.set_speeds(left, right)

    def stop(self) -> None:
        self.set_speeds(0.0, 0.0)

    def rotate_left(self, speed: float = 30.0) -> None:
        self.set_speeds(-speed, speed)

    def rotate_right(self, speed: float = 30.0) -> None:
        self.set_speeds(speed, -speed)

    def drive_straight(self, speed: float = 50.0) -> None:
        self.set_speeds(speed, speed)


# ---------------------------------------------------------------------------
# Real I2C driver — direct port of test_forwardv2.py
# ---------------------------------------------------------------------------

class BLDCMotorDriver(MotorDriver):
    """
    Controls the 2 front M2006 P36 motors via the Powerful BLDC Driver
    boards over I2C. Same init sequence, PID constants, and calibration
    values as test_forwardv2.py.

    Install:
        pip install git+https://github.com/Aw3someAndrew/SteelBar_CircuitPython_powerful_bldc_driver.git
    """

    def __init__(self):
        import board
        import busio
        from steelbar_powerful_bldc_driver import PowerfulBLDCDriver

        self._i2c = busio.I2C(board.SCL, board.SDA)

        log.info("[BLDC] Initialising motors on I2C1...")
        self._lf = self._setup_motor(PowerfulBLDCDriver, MOTOR_CONFIG["LEFT_FRONT"])
        self._rf = self._setup_motor(PowerfulBLDCDriver, MOTOR_CONFIG["RIGHT_FRONT"])
        log.info("[BLDC] Both motors initialised (2 wheel drive)")

    def _setup_motor(self, driver_cls, cfg):
        m = driver_cls(self._i2c, cfg["address"])
        m.set_current_limit_foc(65536)              # 1 amp
        m.set_id_pid_constants(1100, 150)
        m.set_iq_pid_constants(1100, 150)
        m.set_speed_pid_constants(2.5e-2, 2.5e-4, 2e-2)
        m.set_position_region_boundary(250000)
        m.set_ELECANGLEOFFSET(cfg["elec_angle_offset"])
        m.set_SINCOSCENTRE(cfg["sincos_centre"])
        m.set_speed_limit(SPEED_LIMIT)
        m.configure_operating_mode_and_sensor(3, 1)  # FOC, sin/cos encoder
        m.configure_command_mode(12)                  # speed command mode
        m.clear_faults()
        return m

    def _pct_to_units(self, pct: float) -> int:
        units = int((pct / 100.0) * MAX_SPEED_UNITS)
        return max(-MAX_SPEED_UNITS, min(MAX_SPEED_UNITS, units))

    def set_speeds(self, left: float, right: float) -> None:
        # Proven convention: right side positive, left side negative = forward.
        left_units  = -self._pct_to_units(left)
        right_units =  self._pct_to_units(right)

        self._lf.set_speed(left_units)
        self._rf.set_speed(right_units)

        log.debug(f"[BLDC] L={left_units}  R={right_units}")

    def stop(self) -> None:
        for m in (self._lf, self._rf):
            m.set_speed(0)

    def cleanup(self) -> None:
        self.stop()
        for m in (self._lf, self._rf):
            m.clear_faults()
        self._i2c.deinit()


# ---------------------------------------------------------------------------
# PID controller (unchanged)
# ---------------------------------------------------------------------------
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

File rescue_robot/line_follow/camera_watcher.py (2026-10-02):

"""
camera_watcher.py
===================
Single shared background camera thread that both green-marker detection
and spill/silver-tape detection run on top of. Only ONE physical camera
exists on the robot, so green_detector.py and spill_detector.py can't
each open their own Picamera2 instance at the same time -- this replaces
both with one thread that grabs a frame once per tick and runs both
checks on that same frame.

Usage (same shape as the old GreenDetector/SpillDetector):
    watcher = CameraWatcher()
    watcher.start()
    ...
    side, seen_at = watcher.get_green()      # "left"/"right"/None, timestamp
    seen, seen_at = watcher.get_spill()       # True/False, timestamp
    frame, seen_at = watcher.get_frame()      # latest raw BGR frame, for
                                               # on-demand checks like
                                               # bottle_detector.py
    ...
    watcher.stop()
"""

import os
import time
import threading
import logging

import cv2
import numpy as np

from spill_classifier import extract_features, predict_silver

log = logging.getLogger(__name__)

CAM_INDEX = 0

# Image orientation fixes, applied to every frame straight after capture (so
# green side, bottle check, endzone vision etc. all see the corrected image).
MIRROR_LEFT_RIGHT = True    # both True = picture rotated 180 deg (camera is mounted upside down)
FLIP_UP_DOWN = True         # flip the picture top<->bottom
FRAME_WIDTH = 320
FRAME_HEIGHT = 240
FPS = 24

# --- Green marker settings (from green_detector.py) ---
MIN_GREEN_AREA = 300

# --- Green side relative to the BLACK LINE (not the frame centre) ---
BLACK_V_MAX = 70            # pixel darker than this (HSV V) = black line
LINE_COL_MIN_FRAC = 0.5     # a column counts as "the line" if >= this fraction of the
                            # rows level with the green square are black there
                            # (filters out the horizontal crossing line)
# Line tracing (used first): follow the robot's line up from the bottom of the picture
TRACK_MAX_JUMP_PX = 12      # line may shift this much sideways between traced rows
TRACK_MAX_GAP_ROWS = 6      # give up after this many rows with no line
TRACK_WIDE_RUN_PX = 45      # wider than this (and 1.8x the line's own width) = crossing bar
TRACK_MIN_POINTS = 6
TRACK_FIT_POINTS = 15       # fit the line through the last N traced points (just below green)
GREEN_H_LOW,  GREEN_H_HIGH  = 38,  85
GREEN_S_LOW,  GREEN_S_HIGH  = 60, 255
GREEN_V_LOW,  GREEN_V_HIGH  = 40, 255

# --- Spill/silver tape settings (from spill_detector.py) ---
SPILL_BOX_SIZE = 150            # same box size used during sample collection/training
SPILL_MIN_CONFIDENCE = 0.7       # only count it as "seen" above this confidence


class CameraWatcher:
    def __init__(self):
        self._lock = threading.Lock()
        self._green_side = None
        self._green_seen_at = 0.0
        self._green_debug = (None, None)   # (green_cx, line_x) of last detection
        self._spill_seen = False
        self._spill_seen_at = 0.0
        self._frame = None
        self._frame_seen_at = 0.0
        self._running = False
        self._thread = None

    def start(self):
        self._running = True
        self._thread = threading.Thread(target=self._loop, daemon=True)
        self._thread.start()

    def stop(self):
        self._running = False
        if self._thread is not None:
            self._thread.join(timeout=2.0)

    def get_green(self):
        with self._lock:
            return self._green_side, self._green_seen_at

    def get_green_debug(self):
        """(green_cx, line_x) pixel positions from the last green detection."""
        with self._lock:
            return self._green_debug

    def get_spill(self):
        with self._lock:
            return self._spill_seen, self._spill_seen_at

    def get_frame(self):
        """Returns (frame, seen_at) for the most recent captured frame --
        a copy, safe to hand to on-demand checks like bottle_detector.py
        without racing the capture thread. (None, 0.0) if nothing captured
        yet."""
        with self._lock:
            if self._frame is None:
                return None, 0.0
            return self._frame.copy(), self._frame_seen_at
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

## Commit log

2026-07-02 Rename Rasbperry Pi Camera Module 3.stl to design/Picam_topmount.stl
    [Picam_topmount.stl]
2026-09-29 updated files.
    inclusive of spill zone ai training data and calibration data of claw and other servos. new ir sensor code that works. tof i2c bus is 50 not 51
    [spill_samples.csv]
